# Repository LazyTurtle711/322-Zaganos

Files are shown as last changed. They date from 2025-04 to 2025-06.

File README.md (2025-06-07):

# WRO2025 Future Engineers – *322-ZAĞANOS*

Repository of *322-ZAĞANOS* competing in the **World Robot Olympiad (WRO) 2025** Future Engineers category.

---

## 📚 Table of Contents

* [👥 The Team](#the-team)
* [🎯 Challenge Overview](#challenge-overview)
* [🤖 Our Robot](#our-robot)
* [🚗 Mobility Management](#mobility-management)
* [🛠️ Power and Sense Management](#power-and-sense-management)
* [📝 Obstacle Management](#obstacle-management)
* [📽️ Performance Videos](#performance-videos)
* [💰 Cost Analysis](#cost-analysis)
* [⚠️ Reflection and Improvements](#reflections-and-improvements)
* [📂 Resources](#resources) 

---

## 👥 The Team 

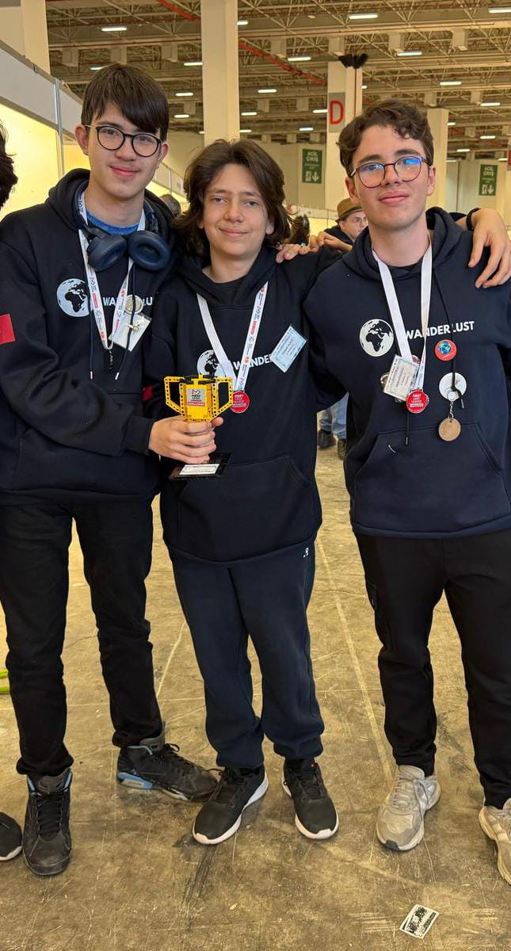
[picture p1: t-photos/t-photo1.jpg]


| Name | Age | School / Institution | Role |
| --- | --- | --- | --- |
| Rüzgar Yılmaz (middle) | 16  | İzmir Bahçeşehir 50. Yıl Fen ve Teknology Lisesi | Electronics |
| Emir Gündoğan (right) | 16  | İzmir Bahçeşehir 50. Yıl Fen ve Teknology Lisesi | Coding |
| Deha Bora Çelik (left) | 16  | İzmir Bahçeşehir 50. Yıl Fen ve Teknology Lisesi | Mechanics (CAD) |

---

## 🎯 Challenge Overview 

The **WRO 2025 Future Engineers** challenge requires developing a **fully autonomous vehicle** that navigates a **dynamic, randomized racetrack** using sensors, computer vision, and control algorithms, completing multiple laps and performing a parallel parking maneuver.

* **Open Challenge**: Complete three (3) laps on a track with randomized interior walls.
* **Obstacle Challenge**: Detect and respond to colored markers:

  * 🟥 Red → Stay right.
  * 🟩 Green → Stay left.
* **Parking**: After laps, identify and execute precise parallel parking in a designated zone.

🔗 **Official Rules**: [WRO 2025 Future Engineers General Rules](https://wro-association.org/wp-content/uploads/WRO-2025-Future-Engineers-Self-Driving-Cars-General-Rules.pdf)

---

## 🤖 Our Robot 
**Controller:**  
We use a **Raspberry Pi 5** for all processing, including sensor fusion, control, and computer vision tasks.

**Vision Sensor:**  
**PixyCam v2** is our key component for detecting colored traffic signs. It allows fast and accurate lane decisions, making it vital for obstacle challenge and direction changes.

**Filament Used:**  
Our chassis and custom mounts were fully 3D-printed using approximately **1 kg of PETG**.

**Steering System:**  
Two synchronized **servo motors** handle front-wheel steering, ensuring smooth directional control—especially useful in tasks like parallel parking.

**Motion Control:**  
A single motor with **ESC** is used for forward/backward movement only, following competition constraints.

**Sensors:**  
- Dual **ultrasonic sensors** on servos detect obstacles on the sides.  
- **MPU6050 gyro** helps the robot stay aligned after each maneuver.  
- **ADS1115 ADC** reads servo positions for dynamic adjustment.

This setup gives us precise obstacle handling and reliable performance in autonomous driving challenges.

---

## 🚗 Mobility Management 

### ⚙️ Chassis & Drivetrain

🧱 Chassis
The chassis is built using a custom frame made from PETG. We designed it to support three levels using spacers between each layer. It keeps everything compact and organized while making sure all the components are easy to access for adjustments or upgrades.

🔽 3 Levels – What’s on Each One

1️⃣ Level 1 – Drive Base & Sensors

This bottom layer includes:

* The DC motor and full drivetrain system
* Wheels, gears, and axles
* Ultrasonic sensors with servos for real-time wall detection

2️⃣ Level 2 – Electronics

This second layer includes:

* 5V 3A Voltage Regulator
* A prototype perfboard for expansion
* All of our electronics

3️⃣ Level 3 – Processing, Vision and Controllers

This third layer includes:

* Raspberry Pi 5 runs the high-level code and processes image data
* The Pixy2 camera is mounted with a servo here for top-view vision
* Servo controller 
* ESC

🚗 Drivetrain

We are using a high-torque brushless DC motor (you’ll see it in the back, with the red end cap). Power goes through a custom planetary gear reduction system and is transferred using bevel and spur gears. It drives both front and rear wheels via shafts, so it’s a kind of 4-wheel-drive layout. The drivetrain is compact, and we’ve geared it to balance speed and torque well. 

And for steering, we’re using a servo-based steering mechanism. Two servos are directly connected to the front wheels, rotating the wheels mechanically. This gives us smooth and responsive real-angle steering, instead of relying on differential wheel speeds. It’s way more precise and especially useful for tasks like tight maneuvers and parallel parking.

---

## 🛠️ Power and Sense Management 

| Component | Specification | Function |
| --- | --- | --- |
| Raspberry Pi 5 | 8 GB RAM, 1.8 GHz CPU | Main controller |
| PixyCam v2 | 60 FPS, color-based | Traffic sign detection |
| Battery | 2S 5000mAh 60C Li-Po | Supplies vehicle with 7.4V |
| Voltage Regulator | LM2596 5V 3A step-down voltage regulator | Provides 5V to logic level components |
| Mosfet | IRLZ44N | Turns the ESC on/off |
| ESC | Quicrun 10BL60 G2 60amp ESC | Allows control over the motor with RPI 5 |
| Motor | Quicrun 3660SL-3700KV-D5.0-G2 | Provides power to wheels |
| ADC | ADS1115 | Allows analog inputs |
| Gyro | MPU6050 | Provides rotational data |
| Servo | MG90S | Allows high-precision control over robot |
| Servo Driver | PCA9685 | Allows control over multiple servos |

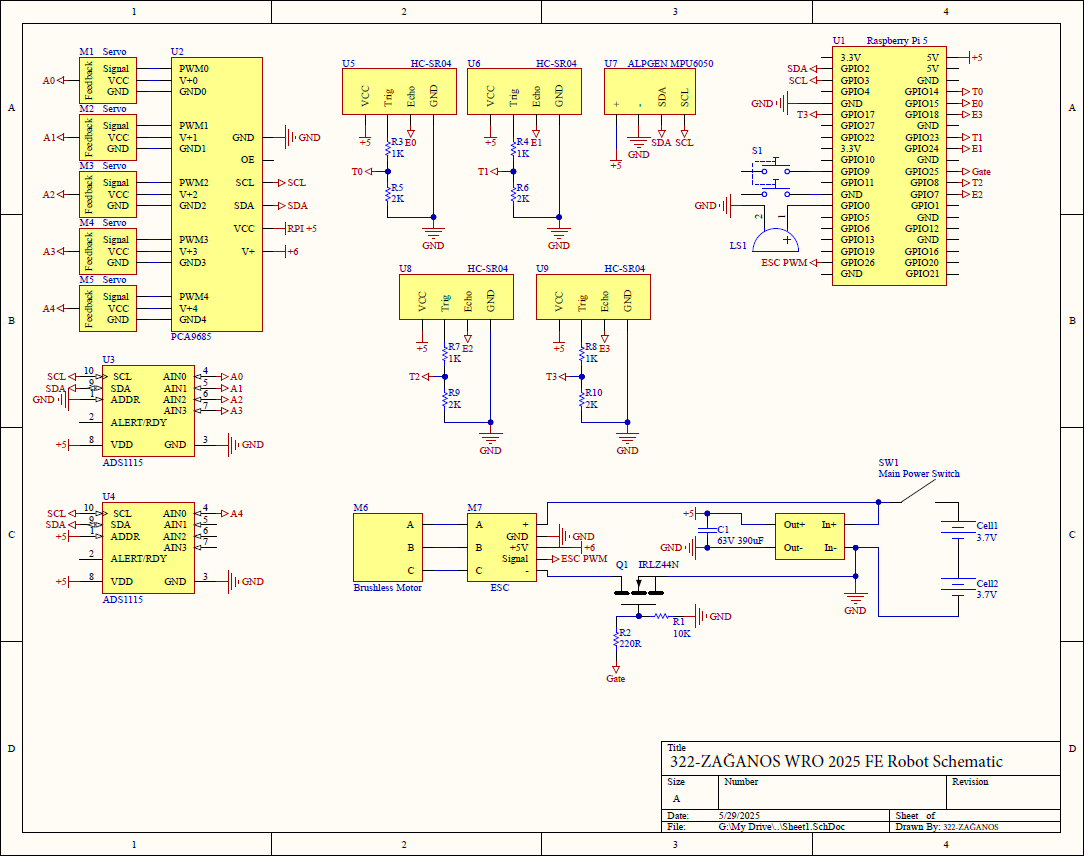
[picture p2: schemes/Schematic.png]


---

## 📝 Obstacle Management 

### 🏁 Open Round

During the Open Round, the robot uses side-mounted ultrasonic sensors on servo motors to determine the appropriate turning direction based on the presence of obstacles. The logic is simple: if there is no obstacle on one side, the robot turns in that direction.

#### 🔎 Turn Decision Logic

```python
leftDistance = get_distance(UltrasonicL)
rightDistance = get_distance(UltrasonicR)

if leftDistance > 200:
    turnLeft()
elif rightDistance > 200:
    turnRight()
else:
    goStraight()
```

This ensures the robot follows a dynamic, obstacle-avoiding trajectory while maintaining consistent navigation throughout the randomized layout.

### 🚧 Obstacle Round

In the Obstacle Round, the robot performs all visual processing using a Pixy2 camera to detect traffic signs (red or green pillars). The camera returns object data in the following format:

```python
block_info = {
    'signature': self.blocks[index].m_signature,  # Color ID (1-7)
    'x': self.blocks[index].m_x,                  # X-coordinate of the block center
    'y': self.blocks[index].m_y,                  # Y-coordinate of the block center
    'width': self.blocks[index].m_width,          # Width of the block
    'height': self.blocks[index].m_height,        # Height of the block
    'angle': self.blocks[index].m_angle,          # Orientation (if applicable)
    'index': self.blocks[index].m_index,          # Pixy tracking ID
    'age': self.blocks[index].m_age               # Number of frames tracked
}
```

### 🧭 Steering Control via Object Tracking

The robot aligns itself with the detected object by comparing its X-coordinate (`block["x"]`) to a defined `target_x`. Both servos are adjusted accordingly to steer:

```python
error = target_x - block["x"]
angle = map(error, -max_deviation, max_deviation, LEFT_SERVO_MAX, RIGHT_SERVO_MIN)
kit.servo[left_servo].angle = angle
kit.servo[right_servo].angle = angle
```

This mechanism enables the robot to stay on course and follow the traffic rules defined by pillar colors.

---

## 📽️ Performance Videos 

> 🔗 **[YouTube Video Link](https://youtu.be/nIWwGna1cYI)**

---

## 💰 Cost Analysis 

### Component Costs

| Component | Quantity | Unit Price (\$) | Total (\$) |
| --- | --- | --- | --- |
| Raspberry Pi 5 | 1 | 102.22$ | 102.22$ |
| PixyCam v2 | 1 | 110.37$ | 110.37$ |
| 3D Filament (PETG)| 1 kg | 21.17$ | 21.17$ |
| Battery | 1 | 52.91$ | 52.91$ |
| Voltage Regulator | 1 | 2.56$ | 2.56$ |
| Mosfet | 1 | 0.64$ | 0.64$ |
| ESC | 1 | 48.87$ | 48.87$ |
| Motor | 1 | 41.35$ | 41.35$ |
| Gyro | 1 | 11.51$ | 11.51$ |
| Servo | 7 | 3.72$ | 26.04$ |
| Servo Driver | 1 | 4.13$ | 4.13$ |
| ADC | 4 | 2.39$ | 9.56$ |
| **Total** | | | **431.33$** |

---

## ⚠️ Reflections & Improvements 
In this section, we reflect on the challenges, design flaws, and execution errors we encountered during development and testing. We also propose concrete improvements for future iterations.

🔧 Key Mistakes & Lessons Learned
| Issue | Description | Proposed Improvement |
| --- | --- | --- |
| Overpowered Motor | The brushless motor we initially selected had excessive torque and RPM, making it difficult to control at low speeds. | Use a lower-KV, sensored motor better suited for precision and control in autonomous driving. |
| Weight & Size | The motor's weight increased the center of mass, affecting stability, and required a large 2-stage planetary gearbox to reduce speed. | Choose a more compact motor with balanced torque output to reduce size and simplify the drivetrain. |
| Gearbox Footprint | The custom gearbox occupies a large portion of the chassis and limited our design flexibility. | Redesign drivetrain layout with modularity in mind; consider belt-driven or simpler reduction mechanisms. |

These mistakes guided us to focus more on practical motor sizing, efficient mechanical design, and weight distribution for better control and future upgrades.

---

## 📂 Resources 

* [Raspberry Pi 5](https://www.raspberrypi.com/products/raspberry-pi-5/)
* [PixyCam v2](https://pixycam.com/)
* ---

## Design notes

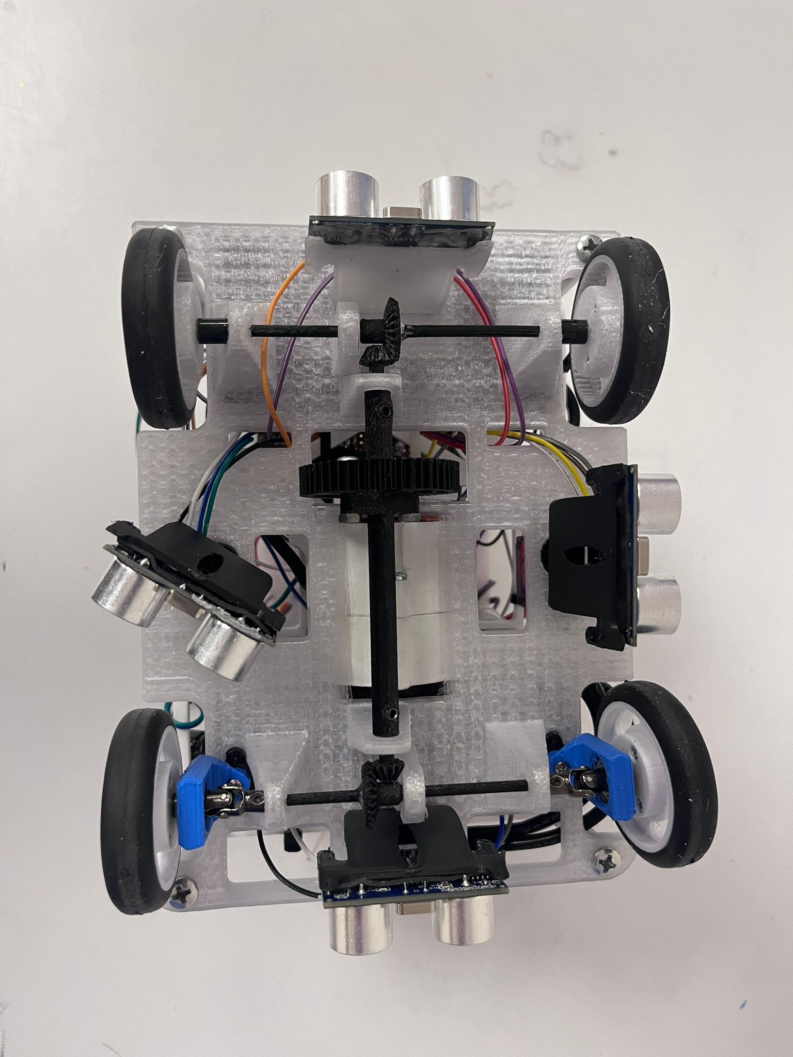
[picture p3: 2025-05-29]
v-photos/IMG-20250529-WA0008.jpg

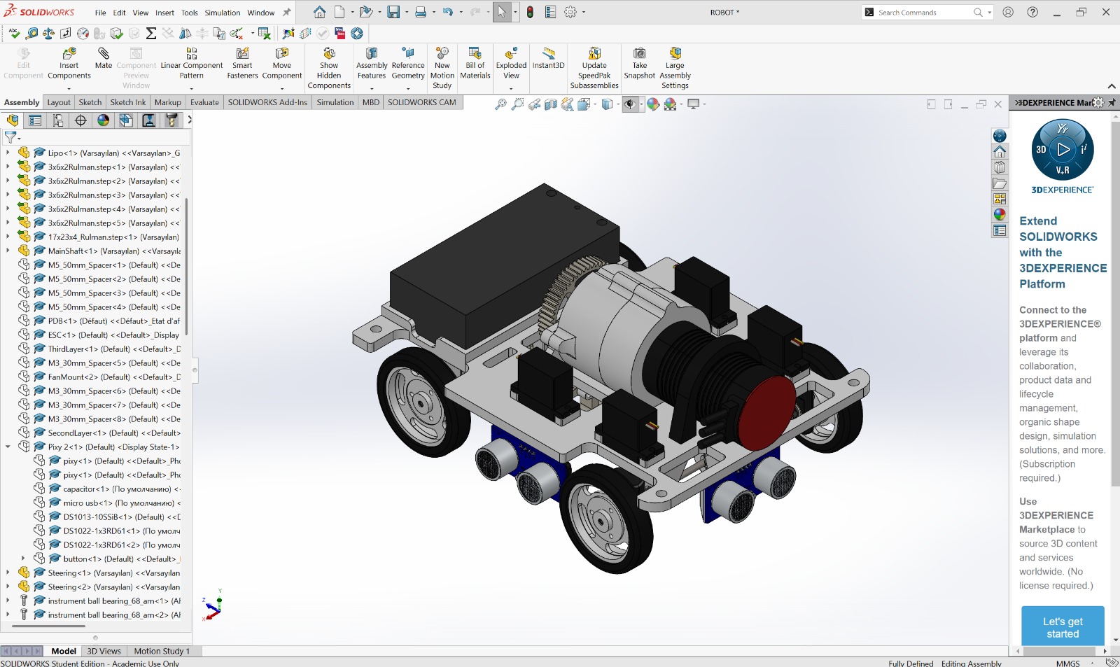
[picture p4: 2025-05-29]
v-photos/IMG-20250529-WA0012.jpg

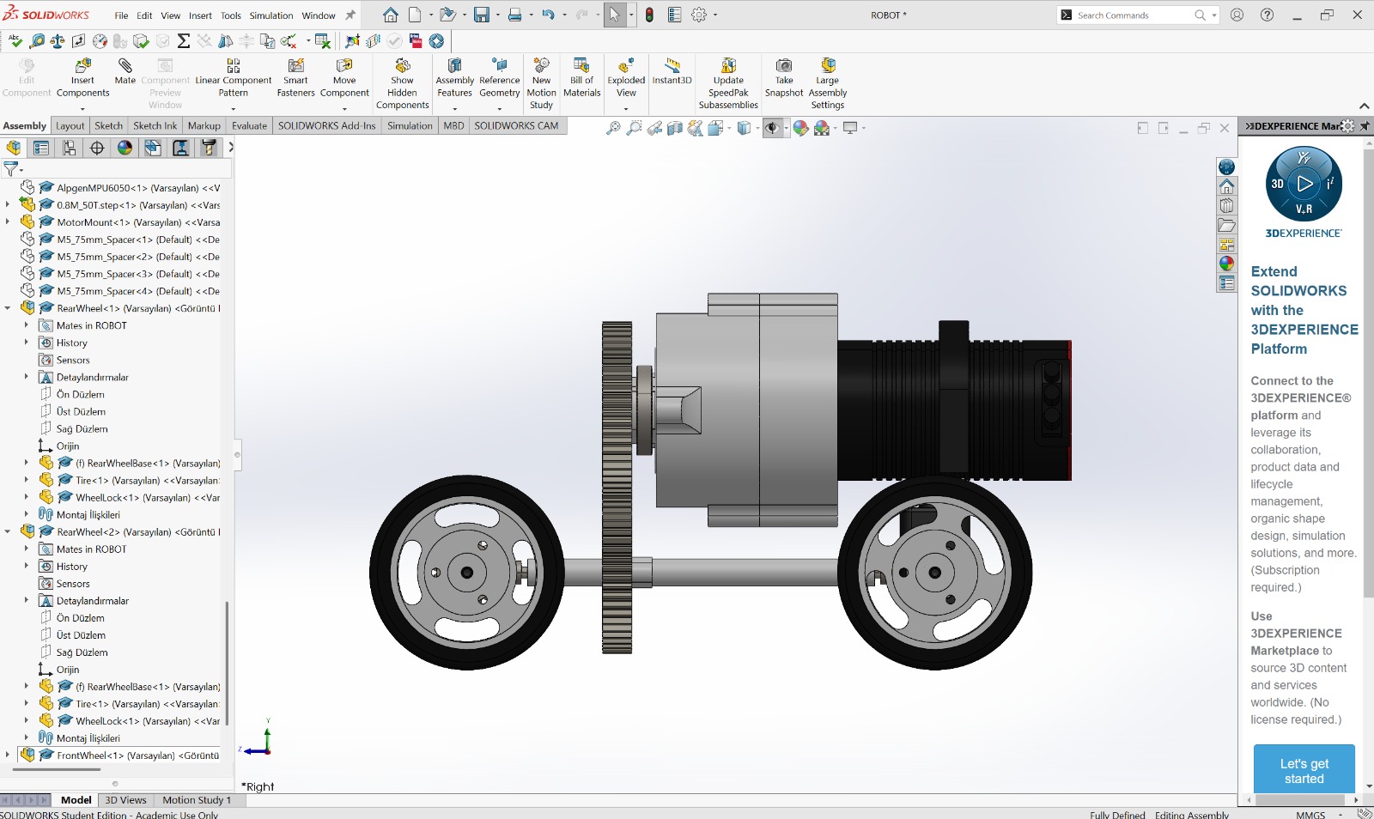
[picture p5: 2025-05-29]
v-photos/IMG-20250529-WA0013.jpg

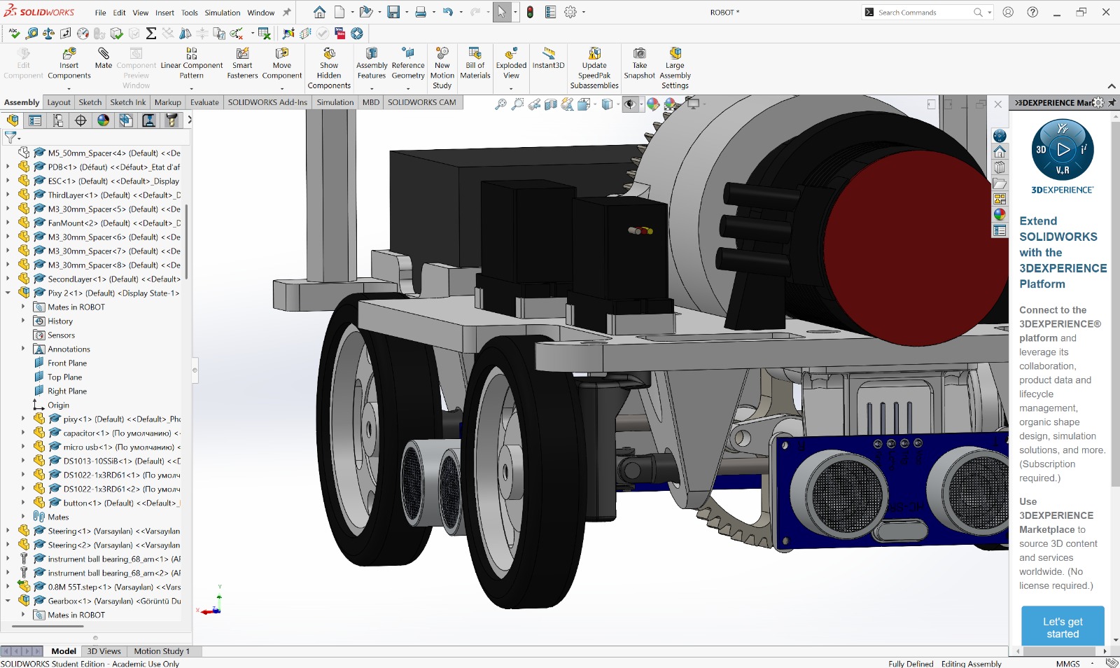
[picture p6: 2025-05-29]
v-photos/IMG-20250529-WA0015.jpg

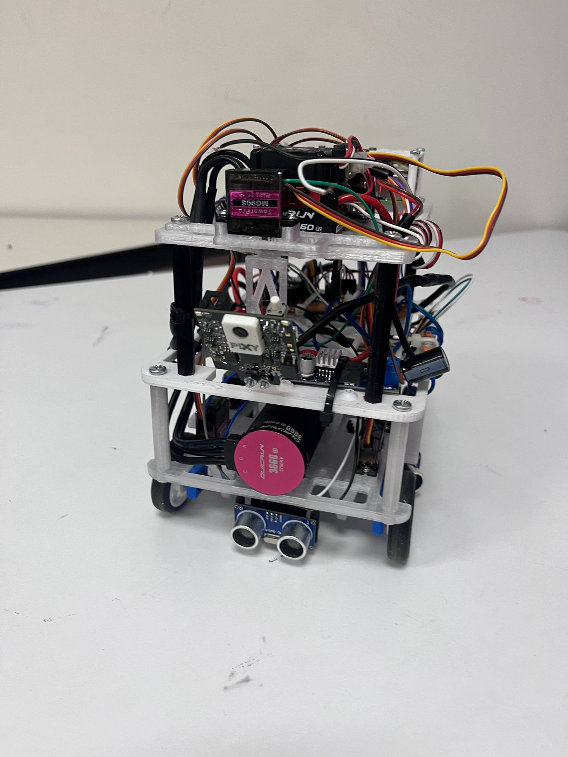
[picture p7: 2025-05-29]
v-photos/IMG-20250529-WA0006.jpg

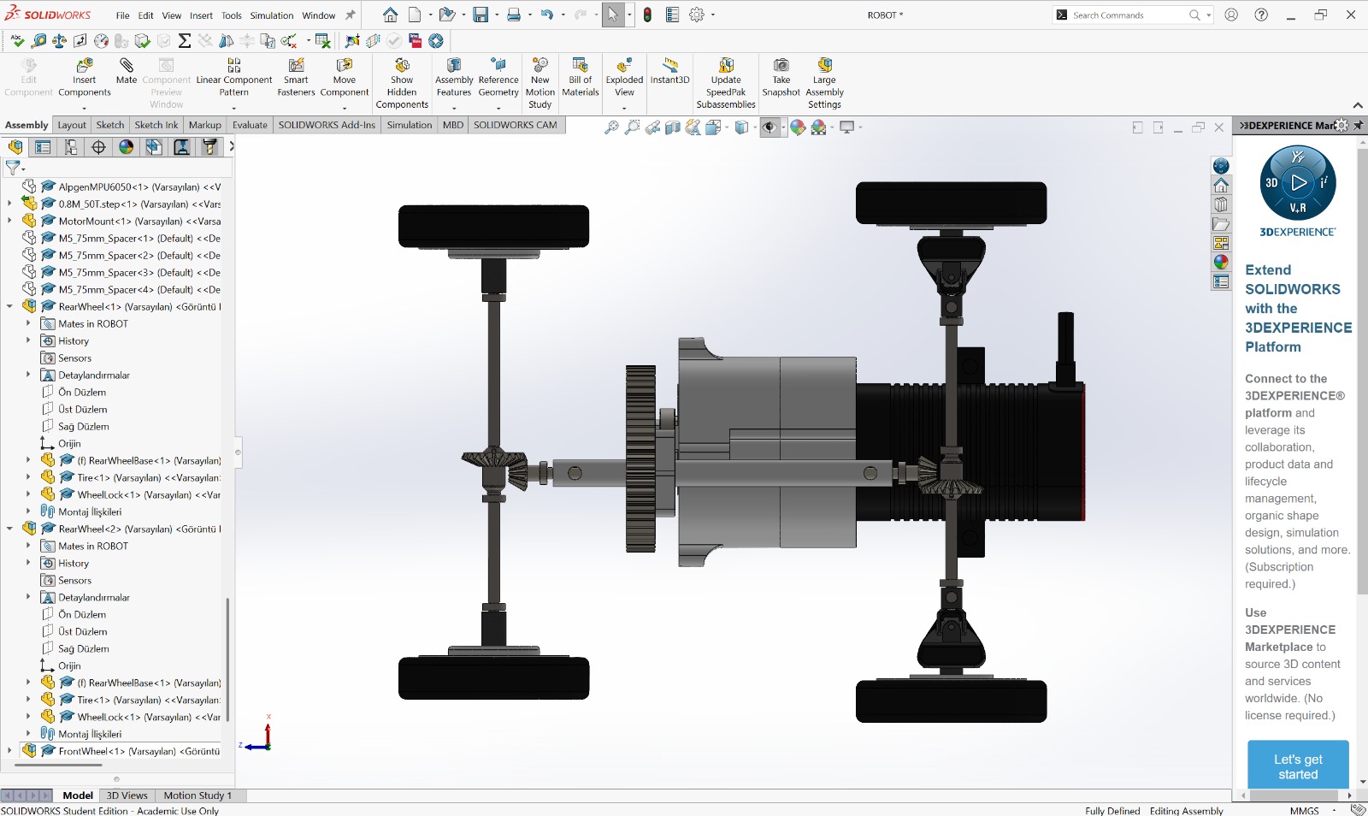
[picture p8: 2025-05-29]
v-photos/IMG-20250529-WA0011.jpg

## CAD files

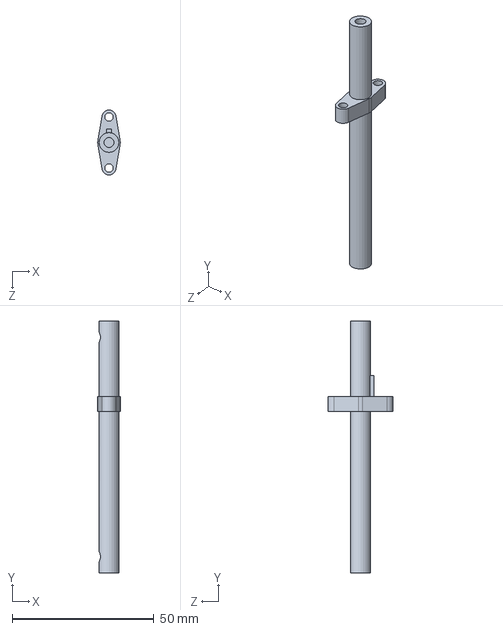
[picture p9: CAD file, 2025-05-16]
models/MainShaft.SLDPRT
8.00 x 89.0 x 23.0 mm

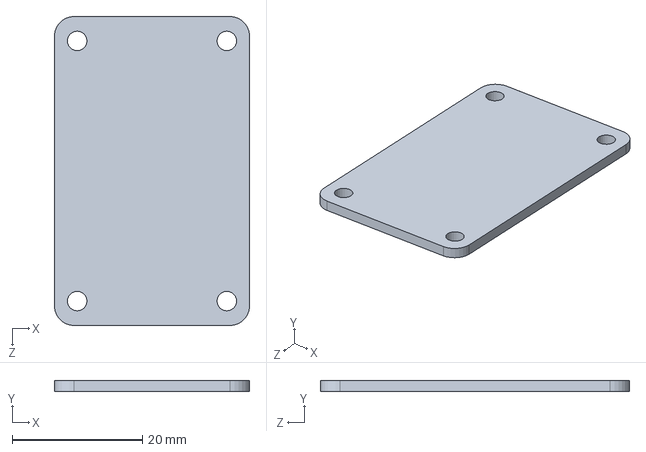
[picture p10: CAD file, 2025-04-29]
models/Pieces/AlpgenMPU6050.SLDPRT
30.0 x 1.75 x 47.5 mm

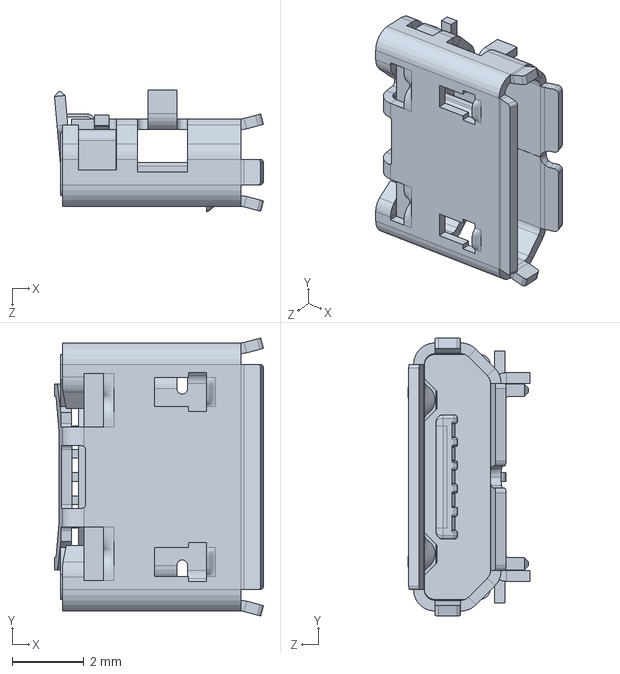
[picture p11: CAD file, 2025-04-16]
models/Pieces/PixyCam/PixyPieces/micro usb.SLDPRT
5.84 x 7.77 x 3.40 mm

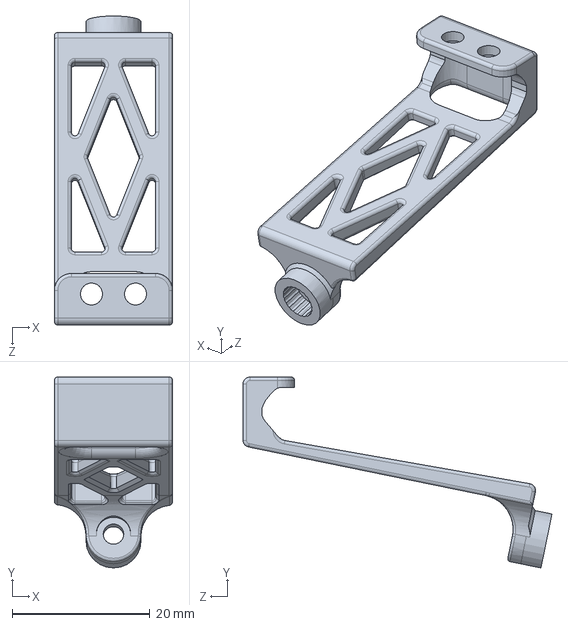
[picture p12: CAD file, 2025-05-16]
models/PixyMount.SLDPRT
17.2 x 27.7 x 44.9 mm

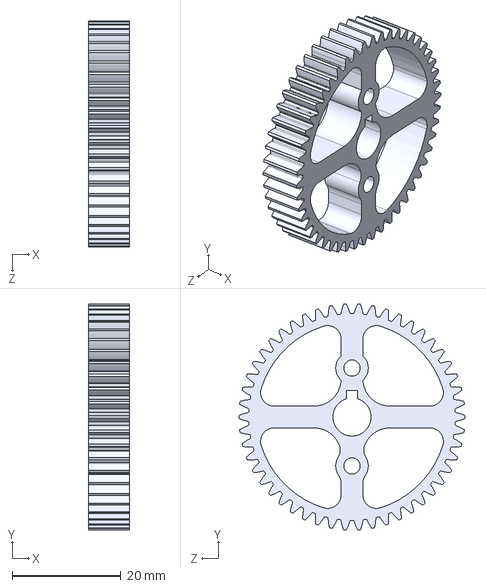
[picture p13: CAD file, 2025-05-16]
models/Planetary/0.8M_50T.STEP
7.50 x 41.5 x 41.6 mm

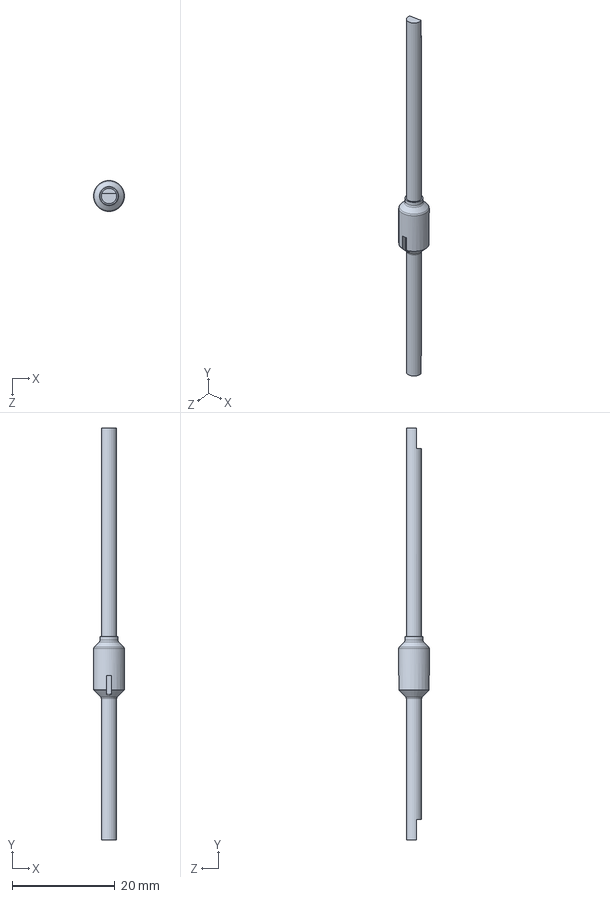
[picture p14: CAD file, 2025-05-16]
models/Shaft/FrontShaft.SLDPRT
6.00 x 80.1 x 6.00 mm

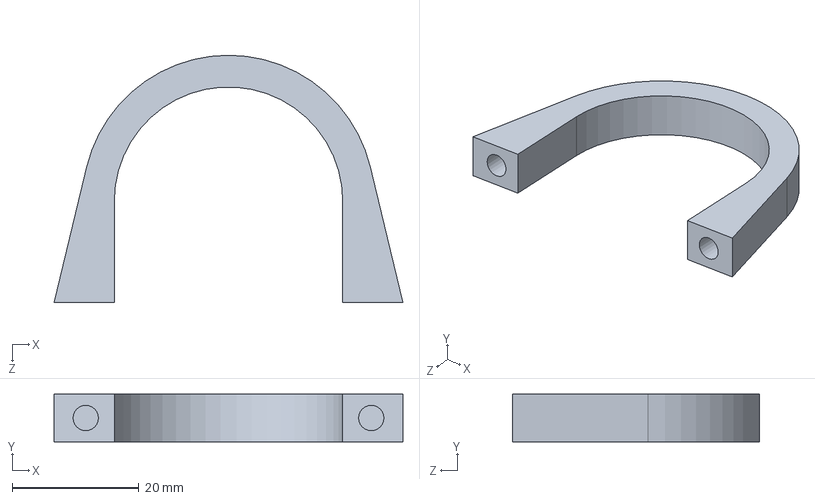
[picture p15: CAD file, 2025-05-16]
models/MotorMount.SLDPRT
55.0 x 7.50 x 39.0 mm

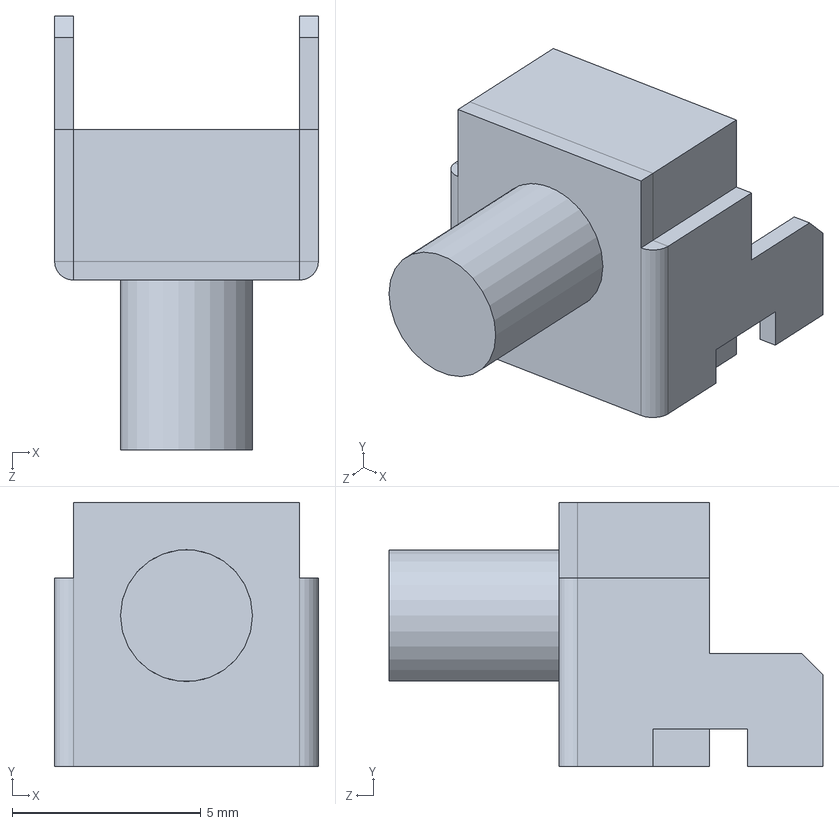
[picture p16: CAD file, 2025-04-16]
models/Pieces/PixyCam/PixyPieces/button.SLDPRT
7.00 x 7.00 x 11.5 mm

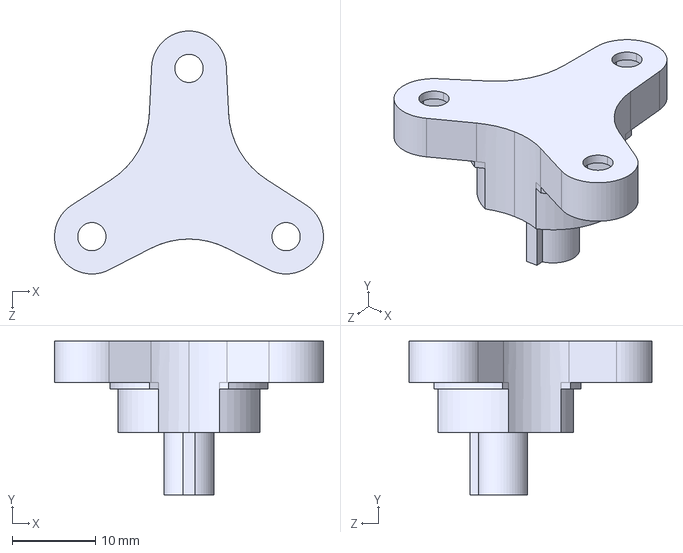
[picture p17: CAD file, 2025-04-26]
models/Planetary/Out2.STEP
32.4 x 18.5 x 29.2 mm

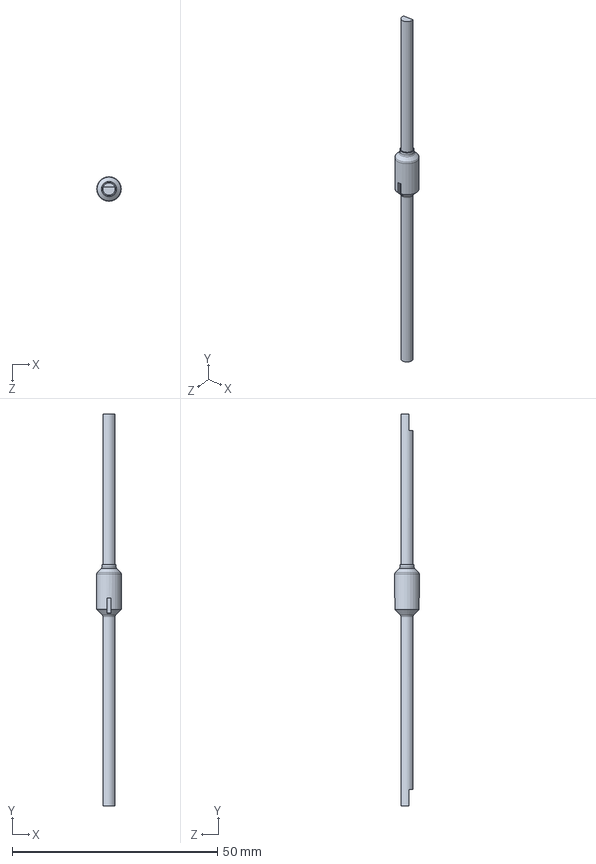
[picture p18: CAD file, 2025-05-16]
models/Shaft/RearShaft.SLDPRT
6.00 x 95.6 x 6.00 mm

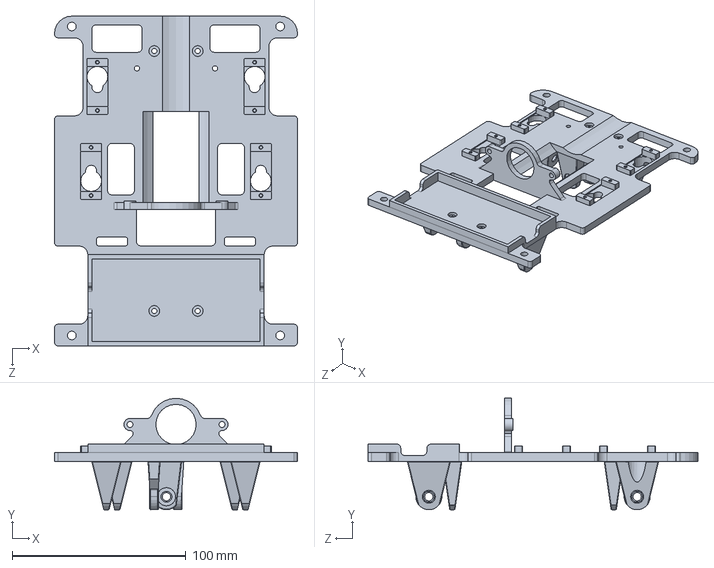
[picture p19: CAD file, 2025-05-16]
models/FirstLayer.SLDPRT
140.0 x 64.2 x 190.0 mm

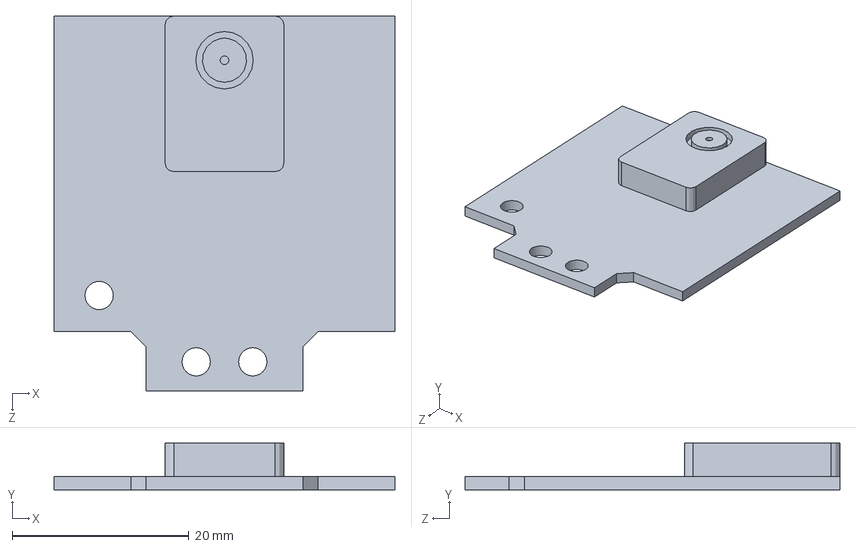
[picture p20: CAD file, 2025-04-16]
models/Pieces/PixyCam/PixyPieces/pixy.SLDPRT
38.5 x 5.30 x 42.4 mm

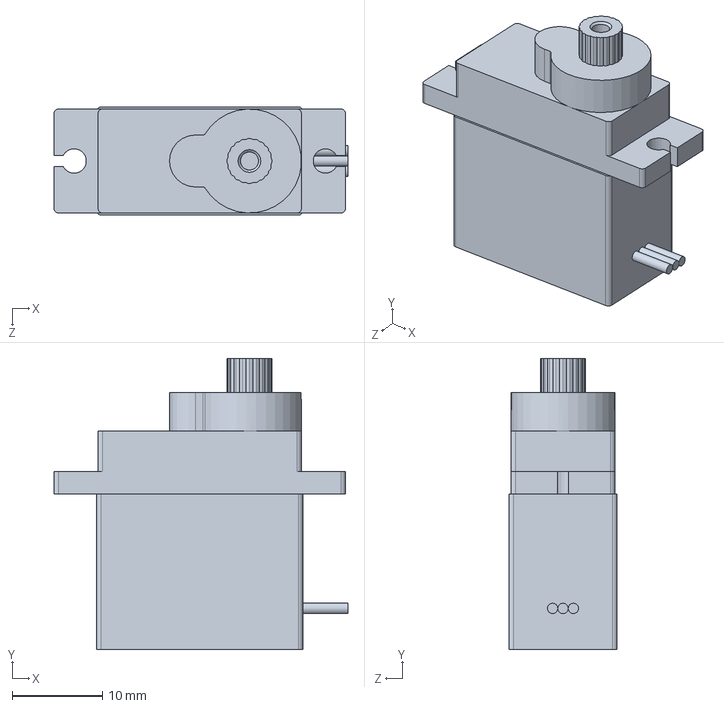
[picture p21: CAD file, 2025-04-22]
models/Pieces/Servo.SLDPRT
32.5 x 32.2 x 12.0 mm

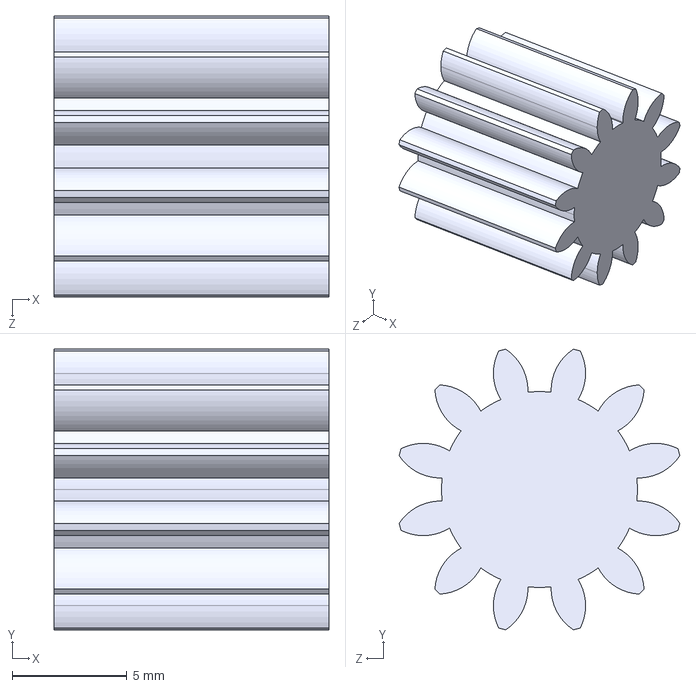
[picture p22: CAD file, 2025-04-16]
models/Planetary/12T_Sun2.STEP
12.0 x 12.2 x 12.2 mm

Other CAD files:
models/Pieces/PixyCam/Pixy 2.SLDASM
models/Shaft/FrontShaftExtra.SLDASM
models/Pieces/Wheel.SLDASM
models/Shaft/BevelPinion12T.STEP
models/FanMount.SLDPRT
models/Pieces/16Bit I2C ADC+PGA - ADS1115.stp
models/Pieces/50x100_Pertinax.SLDPRT
models/Pieces/6x15x5_Bearing.STEP
models/Pieces/ESC.SLDPRT
models/Pieces/Lipo.SLDPRT
models/Pieces/M3_30mm_Spacer.SLDPRT
models/Pieces/M5_50mm_Spacer.SLDPRT
models/Pieces/PCA9685 v18.step
models/Pieces/PDB.SLDPRT
models/Pieces/PixyCam/PixyPieces/DS1013-10SSiB.SLDPRT
models/Pieces/PixyCam/PixyPieces/DS1022-1x3RD61.SLDPRT
models/Pieces/PixyCam/PixyPieces/capacitor.SLDPRT
models/Pieces/Tire.SLDPRT
models/Pieces/WheelBase.SLDPRT
models/Pieces/WheelLock.SLDPRT
models/Planetary/0.8M_50T.SLDPRT
models/Planetary/0.8M_55T.SLDPRT
models/Planetary/0.8M_55T.STEP
models/Planetary/12T_Sun.SLDPRT
models/Planetary/12T_Sun.STEP
models/Planetary/12T_Sun2.SLDPRT
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

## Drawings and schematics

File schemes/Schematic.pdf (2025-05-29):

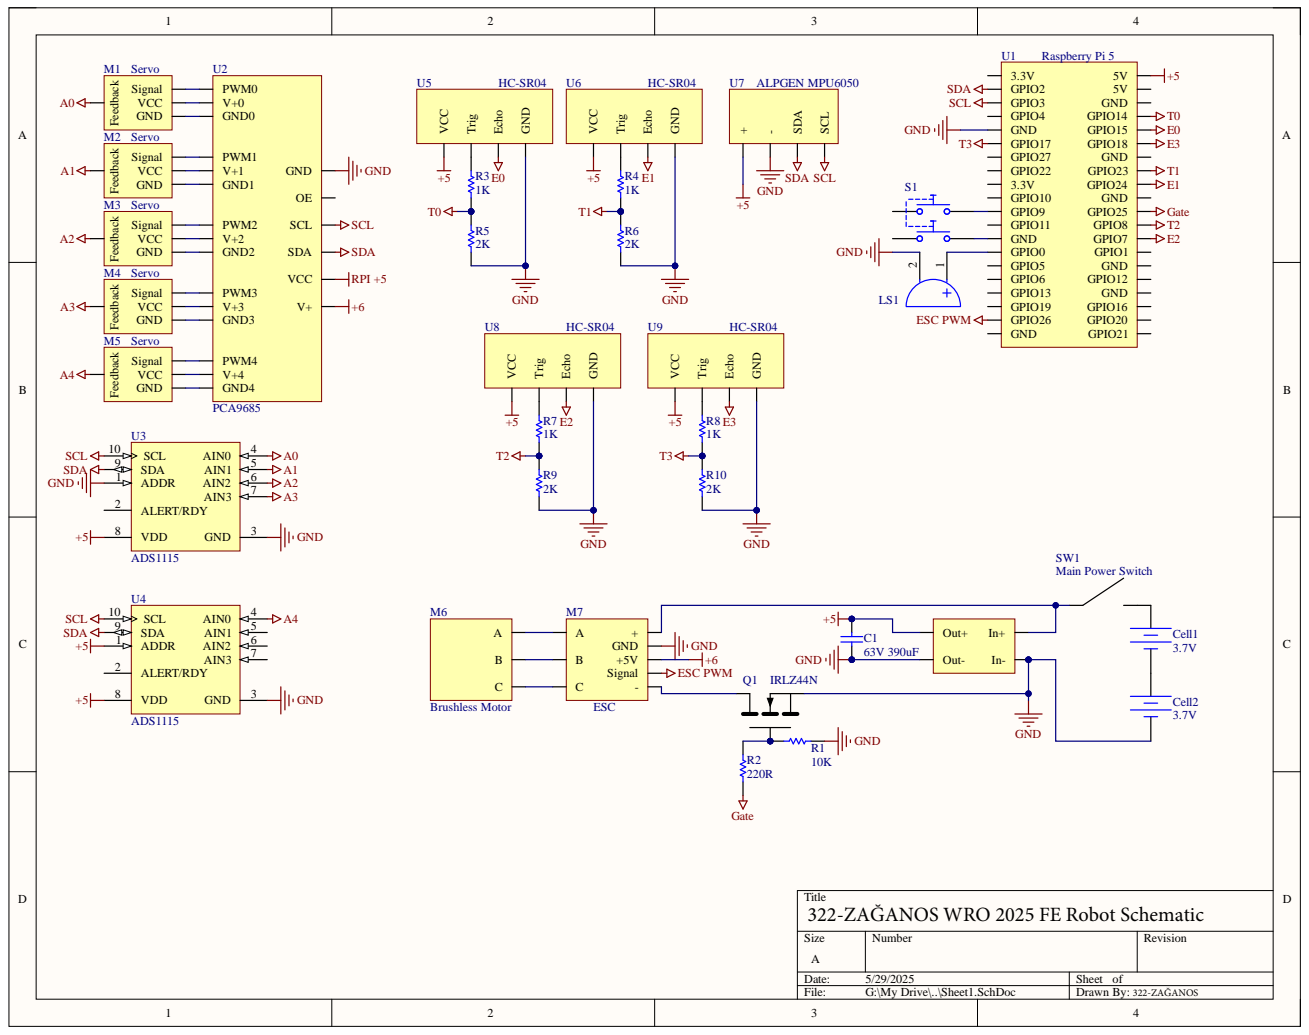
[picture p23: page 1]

Title
322-ZAĞANOS WRO 2025 FE Robot Schematic

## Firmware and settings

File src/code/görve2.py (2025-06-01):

from get_blocks import PixyCam
import time
import board
import busio
import adafruit_ads1x15.ads1115 as ADS
from adafruit_ads1x15.analog_in import AnalogIn
from adafruit_servokit import ServoKit
from gpiozero import DistanceSensor
from gyro import MPU6050
from esc import ESC
from ultrasonic import Ultras
from gpiozero import PWMOutputDevice
from gpiozero import DigitalOutputDevice

class Car:
    def __init__(self):
        self.cam = PixyCam(5)
        self.motor = ESC()

        ultraPins = {
            "front": [5, 7],
            "left": [6, 24],
            "right": [13, 23],
            "back": [19, 8]
        }
        self.ult = Ultras(ultraPins)

        self.mpu = MPU6050()
        self.mpu.reset_gyro()

        self.kit = ServoKit(channels=16)
        self.move_speed = 1.6

        self.default_yaw = 0
        self.turn_cooldown = 2.0
        self.last_turn_time = 0

        self.counter = 0
        self.centerOffset = 0

        self.turnOffset = 0

    def isBlock(self):
        blocks = self.cam.get_blocks()
        return bool(blocks)

    def setCornerTurningYaw(self):
        now = time.time()
        if now - self.last_turn_time < self.turn_cooldown:
            return self.default_yaw, False

        SIDE_TH = 130
        FRONT_TH = 130

        dl = self.ult.getDistance("left")
        dr = self.ult.getDistance("right")
        df = self.ult.getDistance("front")

        print(f"left|{dl} right|{dr} forward|{df}")
        if dl is None or dr is None or df is None:
            return self.default_yaw, False

        if df < FRONT_TH:
            if dl > SIDE_TH and dr <= SIDE_TH:
                self.default_yaw = (self.default_yaw + 90) % 360
                self.last_turn_time = now
                self.counter += 1
                self.centerOffset = 20
                self.turnOffset = 0

                return self.default_yaw, True
            if dr > SIDE_TH and dl <= SIDE_TH:
                self.default_yaw = (self.default_yaw - 90) % 360
                self.last_turn_time = now
                self.counter += 1
                self.centerOffset = -20
                self.turnOffset = 0

                return self.default_yaw, True

        return self.default_yaw, False

    def turn_to_yaw(self, target_yaw, interrupt_on_corner=False):
        print(f"🎯 Yaw'a hizalanma başlıyor: hedef = {target_yaw}°")

        def get_error():
            current = self.mpu.yaw()
            return (target_yaw - current + 540) % 360 - 180

        K = 2.0
        MIN_A, MAX_A = 60, 120
        DEAD_BAND = 0.5
        TARGET_THRESH = 1.0

        while True:
            if interrupt_on_corner:
                _, turning = self.setCornerTurningYaw()
                if turning:
                    print("⚠️ Yaw hizalama sırasında köşe algılandı, iptal.")
                    return False

            if self.ult.getDistance("front") < 15:
                self.motor.set_throttle(1.5)
                break

            self.motor.set_throttle(self.move_speed)

            error = get_error()
            if abs(error) < TARGET_THRESH:
                break

            if abs(error) < DEAD_BAND:
                angle = 90
            else:
                angle = 90 - K * error
                angle = max(MIN_A, min(MAX_A, angle))

            self.kit.servo[0].angle = angle
            self.kit.servo[1].angle = angle
            time.sleep(0.01)

        self.kit.servo[0].angle = 90
        self.kit.servo[1].angle = 90
        return True

    def perform_corner_turn_with_interrupt(self):
        print(f"🔁 Köşe dönüşü başlatıldı: hedef yaw = {self.default_yaw}")

        def get_error():
            current = self.mpu.yaw()
            return (self.default_yaw - current + 540) % 360 - 180

        K = 3.4
        MIN_A, MAX_A = 60, 120
        DEAD_BAND = 0.5
        TARGET_THRESH = 1.0

        while True:
            if self.isBlock():
                print("🟥 Dönüş sırasında blok algılandı! Dönüş iptal.")
                return False

            if self.ult.getDistance("front") < 15:
                self.motor.set_throttle(1.5)
                break

            self.motor.set_throttle(self.move_speed)

            error = get_error()
            if abs(error) < TARGET_THRESH:
                print("✅ Dönüş tamamlandı.")
                break

            if abs(error) < DEAD_BAND:
                angle = 90
            else:
                angle = 90 - K * error
                angle = max(MIN_A, min(MAX_A, angle + self.turnOffset))
 
            self.kit.servo[0].angle = angle 
            self.kit.servo[1].angle = angle
            time.sleep(0.01)

        self.kit.servo[0].angle = 90
        self.kit.servo[1].angle = 90
        return True

    def calculate_dynamic_yaw(self, x, signature, current_yaw, frame_width=316, max_yaw_offset=30):
        center_x = frame_width / 2
        distance_from_center = abs(x - center_x)
        inverse_weight = 1 - (distance_from_center / center_x)

        direction = 1 if signature == 2 else -1
        yaw_offset = direction * inverse_weight * max_yaw_offset
        target_yaw = (current_yaw + yaw_offset) % 360
        return target_yaw

    def run(self):
        while True:
            blocks = self.cam.get_blocks()

            yaw, turning = self.setCornerTurningYaw()
            self.default_yaw = yaw

            if turning:
                success = self.perform_corner_turn_with_interrupt()
                if not success:
                    continue

            if self.isBlock():
                x = blocks[0]['x']
                sig = blocks[0]['signature']
                target = self.calculate_dynamic_yaw(x, sig, self.mpu.yaw())
                print(f"🎯 Hedef yaw: {target}")
                self.turn_to_yaw(target)

                while self.isBlock():
                    self.motor.set_throttle(self.move_speed)
                    time.sleep(0.05)

                print("✅ Blok geçildi, eski yönüne dönülüyor...")
                time.sleep(0.15)

                alignment_done = self.turn_to_yaw(self.default_yaw, interrupt_on_corner=True)
                if not alignment_done:
                    print("➡️ Hizalama iptal edildi, köşe dönüşüne geçiliyor.")
                    self.perform_corner_turn_with_interrupt()

            else:
                self.motor.set_throttle(1.6)
                print("⛔ Blok yok.")
            time.sleep(0.1)


if __name__ == "__main__":
    car = Car()
    car.run()

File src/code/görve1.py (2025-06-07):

import time
import board
import busio
import adafruit_ads1x15.ads1115 as ADS
from adafruit_ads1x15.analog_in import AnalogIn
from adafruit_servokit import ServoKit
from gpiozero import DistanceSensor
from gyro import MPU6050
from esc import ESC
from ultrasonic import Ultras
from gpiozero import PWMOutputDevice  # Import PWM output for controlling ESC
from gpiozero import DigitalOutputDevice
from gpiozero import Button
class AutonomousCar:
    def __init__(self):
        self.button = Button(12)
        self.motor = ESC()

        # Ultrasonik sensörler
        ultraPins = { # Echo, Trigger
        "front": [5, 7],
        "left": [6, 24],
        "right": [13, 23],
        "back": [19, 8]
        }
        self.ult = Ultras(ultraPins)


        # Yaw sensörü
        self.last_value = 0
        self.mpu = MPU6050()
        self.mpu.reset_gyro()

        # Servo sürücü
        self.kit = ServoKit(channels=16)

        # ESC motor kontrolü
        self.move_speed = 1.6

        # Başlangıç yönü (0°)
        self.default_yaw    = 0
        self.turn_cooldown = 2.0
        self.last_turn_time = 0

        self.counter = 0
        self.centerOffset = 0

    def setCornerTurningYaw(self):
        now = time.time()
        if now - self.last_turn_time < self.turn_cooldown:
            return self.default_yaw, False

        SIDE_TH  = 115
        FRONT_TH = 170

        dl = self.ult.getDistance("left")  
        dr = self.ult.getDistance("right")
        df = self.ult.getDistance("front")

        print(f"left|{dl} right|{dr} forward|{df}")
        if dl is None or dr is None or df is None:
            return self.default_yaw, False

        if df < FRONT_TH:
            if dl > SIDE_TH and dr <= SIDE_TH:
                self.default_yaw    = (self.default_yaw + 90) % 360
                self.last_turn_time = now
                self.counter += 1
                self.centerOffset = 20
                return self.default_yaw, True
            if dr > SIDE_TH and dl <= SIDE_TH:
                self.default_yaw    = (self.default_yaw - 90) % 360
                self.last_turn_time = now
                self.counter += 1
                self.centerOffset = -20
                return self.default_yaw, True
                

        return self.default_yaw, False

    def turn_to_yaw(self, target_yaw):
        """
        target_yaw’a en kısa yönden dönüp, |error| < TARGET_THRESH olana dek sürer.
        Bu süreçte motor kapatılmaz; sürekli ileri hareket devam eder.
        """
        print(f"🎯 Yaw'a hizalanma başlıyor: hedef = {target_yaw}°")

        def get_error():
            try:
                current = self.mpu.yaw()
                return (target_yaw - current + 540) % 360 - 180
            except:
                time.sleep(0.05)
                current = self.mpu.yaw()
                return (target_yaw - current + 540) % 360 - 180


        K = 5
        MIN_A, MAX_A = 60, 120
        DEAD_BAND = 0.35
        TARGET_THRESH = 0.79

        # Hedefe ulaşana dek servo yönlendirme ve sürekli motor ileri
        while True:
            # Motor desteği
            if self.ult.getDistance("front") < 15:
                break

            self.motor.set_throttle(self.move_speed)

            error = get_error()
            if abs(error) < TARGET_THRESH:
                break

            if abs(error) < DEAD_BAND:
                angle = 90
            else:
                angle = 90 - K * error
                angle = max(MIN_A, min(MAX_A, angle))

            self.kit.servo[0].angle = angle 
            self.kit.servo[1].angle = angle
            time.sleep(0.01)

        # Hizalama sonrası direksiyon düz
        self.kit.servo[0].angle = 90
        self.kit.servo[1].angle = 90

    def alignToUltrasonic(self, offset_cm=0):  # offset_cm > 0 ise sağa, < 0 ise sola hizalan
        right = self.ult.getDistance("right")
        left = self.ult.getDistance("left")

        # İstenen farkı oluştur: sağdan soldan offset kadar fazla olmalı
        target_diff = offset_cm  # örn. 20 cm sağa kaymak istiyorsan sağ > sol olacak

        diff = right - left

        # Gerçek fark ile hedef fark arasındaki hata
        error = diff - target_diff

        if abs(error) < 3:  # yeterince yakınsa hizalı say
            self.turn_to_yaw(self.default_yaw)
        elif error > 0:
            self.turn_to_yaw(self.default_yaw - 20)  # sola düzelt
        else:
            self.turn_to_yaw(self.default_yaw + 20)   


    def run(self):
        print("▶ Sürekli sürüş + koşullu yaw dönüş modunda.")
        while True:
            yaw, turning = self.setCornerTurningYaw()
            self.default_yaw = yaw
            print(turning)

            self.turn_to_yaw(self.default_yaw)
            print(f"DefaultYaw: {self.default_yaw}")
                # Düz git + nötr servo

            if self.counter == 12:
                time.sleep(0.3)
                self.motor.set_throttle(1.5)
                break
    

            time.sleep(0.025)


if __name__ == "__main__":
    car = AutonomousCar()
    while not car.button.is_pressed:
        pass
    time.sleep(1.5)
    car.run()
#(-20 right) + left

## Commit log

2025-04-16 First commit (Models)
    [0.8M_50T.SLDPRT, 0.8M_50T.STEP, 0.8M_55T.SLDPRT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]
2025-04-17 Servo and Main Shaft Fix
    [FirstLayer.SLDPRT, MainShaft.SLDPRT, PixyMount.SLDPRT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]
2025-04-22 General improvement
    Strengthened parts
    Re-designed shaft holes
    Added front ultrasonic sensor
    [FirstLayer.SLDPRT, M3_25mm_Spacer.SLDPRT, M3_30mm_Spacer.SLDPRT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]
2025-04-22 Finished ultrasonic sensors
    [UltraMountFront.SLDPRT, UltraMountMain.SLDPRT, UltraMountSide.SLDPRT]
2025-04-26 Shaft rework
    Replaced stock shafts with custom 3D printed ones
    [BevelGear24.SLDPRT, BevelPinion12.SLDPRT, FirstLayer.SLDPRT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]
2025-04-27 İmproved schematic
2025-04-29 Model improvements
    Finished shaft replacement
    Added/Mounted gyroscope model
    Increased module of the bevel gears making them easier to 3D print
    Changed side ultrasonic mounts
    [AlpgenMPU6050.SLDPRT, BevelGear24.SLDPRT, BevelGear24T.SLDPRT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]
2025-04-30 Corrected ultrasonic wiring
2025-04-30 Started writing servo and ultrasonic code
2025-05-16 Finished CAD
    [0.8M_50T.SLDPRT, 0.8M_50T.STEP, FirstLayer.SLDPRT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]
2025-05-28 Update Power and Sense Management
2025-05-29 Updated schematics
2025-05-29 Added schematic image to README
2025-05-30 Finished ultrasonic integration
2025-06-01 Removed unused steering.py
